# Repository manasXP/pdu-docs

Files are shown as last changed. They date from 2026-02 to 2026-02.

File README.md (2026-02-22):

# 30 kW Power Delivery Unit (PDU) — Design Documentation

Design documentation for a **30 kW DC fast-charging power module** intended for EV charging infrastructure. The module converts 3-phase AC to adjustable high-voltage DC, and 5 units stack via CAN bus to deliver 150 kW.

## Key Specifications

| Parameter | Value |
|---|---|
| Input | 3-phase 260–530 VAC, up to 60 A, PF ≥ 0.99 |
| Output | 150–1000 VDC, 0–100 A, 30 kW constant power |
| Efficiency | > 96% peak (SiC-based, targeting > 98%) |
| Topology | Vienna Rectifier PFC + 3-phase interleaved LLC DC-DC |
| Controller | STM32G474RE (170 MHz, HRTIM) |
| Stacking | 5 modules via CAN bus → 150 kW |
| Form factor | ~455 × 300 × 94 mm, fan-cooled, < 17 kg |
| Standards | IEC 61851-23, IEC 62368-1, UL 2202, CE, OCPP 1.6, ISO 15118 |

## Multi-Board Architecture

The PDU is split into 5 separate PCBs interconnected by power bus bars and signal harnesses:

| Board | Function | Layers | Size |
|---|---|---|---|
| **Power Entry** | AC input protection (NTC inrush, bypass relays), DC output contactor | 2 | 150 × 120 mm |
| **AC-DC** | Vienna Rectifier PFC — EMI filter, 3-phase rectification, DC bus caps | 6 | 250 × 180 mm |
| **DC-DC** | LLC Resonant converter — primary bridge, transformers, secondary rectifier | 6 | 250 × 180 mm |
| **Controller** | STM32G474RE, CAN bus, analog conditioning, OCPP/ISO 15118 | 4 | 120 × 100 mm |
| **Aux PSU** | Isolated supplies — gate drive (+18 V/−5 V), logic (3.3/5 V), fan (12 V) | 4 | 100 × 80 mm |

## Repository Structure

```
pdu-docs/
├── __init.md                          # Project definition and specifications
├── CLAUDE.md                          # Claude Code workspace guidance
│
├── docs/                              # Design documentation
│   ├── 01-Topology Selection.md       # Vienna PFC + 3-phase interleaved LLC
│   ├── 02-Magnetics Design.md        # LLC resonant tank, transformer, inductor
│   ├── 03-LLC Gain Curve Verification.md  # FHA + ngspice simulation
│   ├── 04-Thermal Budget.md          # Loss breakdown, junction temps, cooling
│   ├── 05-EMI Filter Design.md       # EN 55032 Class B, surge, inrush
│   ├── 06-Firmware Architecture.md   # STM32G474 HRTIM, ADC, control loops
│   ├── 06-Firmware-Design/           # Firmware implementation details (8 docs)
│   │   ├── __init.md                 # Index and reading order
│   │   ├── 01-Application State Machine.md
│   │   ├── 02-Power-On Sequence and Ramp Control.md
│   │   ├── 03-Fault State Machine and Recovery.md
│   │   ├── 04-LLC Burst Mode.md
│   │   ├── 05-CAN Master and Module Stacking.md
│   │   ├── 06-ADC Pipeline and DMA Configuration.md
│   │   └── 07-Neutral Point Balancing.md
│   ├── 07-BOM and Cost Analysis.md   # Per-module BOM, cost @ 100/500 qty
│   ├── 08-Power-On Sequence and Inrush Management.md
│   ├── 09-Protection and Safety.md   # OVP/OCP/OTP, insulation, hipot,compliance
│   ├── 10-Mechanical Integration.md  # Enclosure,heatsink,fans,bus bars,assembly
│   │
│   └── 07-PCB-Layout/                # Multi-board PCB layout documentation
│       ├── __init.md                  # 5-board overview and design targets
│       ├── 00-Board Partitioning.md   # Inter-board interfaces, connectors, grounding
│       ├── AC-DC/                     # Vienna PFC board (7 docs)
│       │   ├── __init.md
│       │   ├── 01-Stack-Up and Layer Assignment.md
│       │   ├── 02-Power Loop Analysis.md
│       │   ├── 03-Gate Driver Layout.md
│       │   ├── 04-Thermal Layout.md
│       │   ├── 05-EMI-Aware Layout.md
│       │   └── 06-Creepage and Clearance.md
│       ├── DC-DC/                     # LLC converter board (7 docs)
│       │   ├── __init.md
│       │   ├── 01-Stack-Up and Layer Assignment.md
│       │   ├── 02-Power Loop Analysis.md
│       │   ├── 03-Gate Driver Layout.md
│       │   ├── 04-Thermal Layout.md
│       │   ├── 05-EMI-Aware Layout.md
│       │   └── 06-Creepage and Clearance.md
│       ├── Controller/                # Digital control board (6 docs)
│       │   ├── __init.md
│       │   ├── 01-Stack-Up and Layer Assignment.md
│       │   ├── 02-Signal Integrity.md
│       │   ├── 03-Communication Interfaces.md
│       │   ├── 04-Power Distribution.md
│       │   └── 05-EMC and Grounding.md
│       ├── Aux-PSU/                   # Auxiliary power supply board (6 docs)
│       │   ├── __init.md
│       │   ├── 01-Stack-Up and Layer Assignment.md
│       │   ├── 02-Isolated Converter Layout.md
│       │   ├── 03-Thermal Layout.md
│       │   ├── 04-Output Filtering and Regulation.md
│       │   └── 05-Safety and Isolation.md
│       └── Power-Entry/               # Contactor and relay board (1 doc)
│           └── __init.md
│
│   └── 12-Project-Management/            # Consolidated project management
│       ├── __init.md                     # Epic overview, Gantt, milestones, gate reviews
│       ├── EP-01 Design Review and Procurement.md    (18 stories)
│       ├── EP-02 Rev A Prototype Build.md            (14 stories)
│       ├── EP-03 Firmware Bring-Up.md                (16 stories)
│       ├── EP-04 System Integration.md               (15 stories)
│       ├── EP-05 Rev B Prototype.md                  (12 stories)
│       ├── EP-06 Firmware Maturation.md              (14 stories)
│       ├── EP-07 Certification Prep.md               (13 stories)
│       ├── EP-08 Pre-Production Validation.md        (11 stories)
│       ├── EP-09 Production Release.md               (10 stories)
│       ├── Budget Estimate.md            # $390k–$615k detailed budget
│       ├── Risk Register.md              # 21 risks, 5×5 scoring matrix
│       └── Commissioning Procedure.md    # 7-stage field deployment
│
├── research/                          # Research notes and trade studies
│   ├── 3-Phase PFC Topology Selection.md
│   ├── DC-DC Topology Trade Study.md
│   ├── Commercial Reference Designs Survey.md
│   ├── EMC-EMI Limits and Filter Design.md
│   └── SiC Device Thermal Parameters.md
│
└── sim/                               # Simulation files
    ├── llc_fha_gain.py                # First Harmonic Approximation gain model
    ├── llc_ngspice_sweep.py           # ngspice parameter sweep automation
    ├── llc_halfbridge.cir             # SPICE netlist — LLC half-bridge
    ├── llc_sweep.cir                  # SPICE netlist — frequency sweep
    ├── llc_gain_curves.png            # FHA gain curves output
    ├── llc_spice_vs_fha.png           # SPICE vs FHA comparison
    └── llc_zvs_detail.png             # ZVS boundary detail plot
```

## Documentation Overview

### Design Documents (`docs/`)

| # | Document | Status |
|---|---|---|
| 01 | **Topology Selection** — Vienna PFC + 3-phase interleaved LLC | Approved |
| 02 | **Magnetics Design** — LLC resonant tank (Lr, Lm, Cr), transformer | Draft |
| 03 | **LLC Gain Curve Verification** — FHA model + ngspice validation | Draft |
| 04 | **Thermal Budget** — System losses, junction temperatures, cooling | Draft |
| 05 | **EMI Filter Design** — EN 55032 Class B, CM/DM filtering | Draft |
| 06 | **Firmware Architecture** — STM32G474RE HRTIM, control loops, CAN | Draft |
| 06 | **Firmware Design** — Implementation details: state machine, ramps, faults, burst mode, CAN master, ADC/DMA, NP balance (8 sub-documents) | Draft |
| 07 | **BOM and Cost Analysis** — Component selection, cost at volume | Draft |
| 07 | **PCB Layout** — Multi-board layout across 5 PCBs (29 sub-documents) | Draft |
| 08 | **Power-On Sequence** — Startup/shutdown, inrush, pre-charge | Draft |
| 09 | **Protection and Safety** — OVP/OCP/OTP, insulation, hipot, compliance | Draft |
| 10 | **Mechanical Integration** — Enclosure, heatsink, fans, bus bars | Draft |
| 12 | **Project Management** — 9 epics (123 stories), Gantt timeline, milestones, gate reviews, budget estimate, risk register, commissioning procedure (13 documents) | Draft |

### PCB Layout (`docs/07-PCB-Layout/`)

The PCB layout section contains **29 documents** organized by board:

- **Power Entry Board** (1 doc) — 2-layer, NTC inrush limiting, bypass relays, DC output contactor, AC/DC zone separation
- **AC-DC Board** (7 docs) — 6-layer, Vienna PFC power loops (≤10 nH), SiC gate drivers, 530 VAC creepage
- **DC-DC Board** (7 docs) — 6-layer, LLC primary loop (≤8 nH, critical margin), 4 kV primary-secondary isolation
- **Controller Board** (6 docs) — 4-layer digital, signal integrity, CAN/OCPP/ISO 15118 interfaces
- **Aux PSU Board** (6 docs) — 4-layer, flyback converter, reinforced isolation from 920 VDC bus

### Research Notes (`research/`)

Trade studies and component evaluations supporting the design decisions:
- PFC topology comparison (Vienna vs B6, Swiss, two-level VSI)
- DC-DC topology comparison (LLC vs DAB, PSFB, CLLC, SRC)
- Commercial reference design survey (Wolfspeed, ST, Infineon, onsemi, TI, ADI)
- EMC/EMI limits and filter design methodology
- SiC MOSFET thermal characterization and package comparison

### Simulations (`sim/`)

Python scripts and SPICE netlists for LLC resonant converter verification:
- First Harmonic Approximation (FHA) gain model
- ngspice transient simulation and frequency sweep
- Gain curve validation (FHA vs SPICE)
- ZVS boundary analysis

## Viewing These Documents

This repository is designed as an [Obsidian](https://obsidian.md/) vault. For the best experience:

1. Clone the repo
2. Open the folder as a vault in Obsidian
3. Navigate using `[[wiki links]]` — all internal links resolve within the vault

The documents are also readable as standard Markdown in any viewer (GitHub, VS Code, etc.), though `[[wiki links]]` will not be clickable outside Obsidian.

## Author

**Manas Pradhan**

## License

All rights reserved JouleWorX LLP 2025. This documentation is proprietary.

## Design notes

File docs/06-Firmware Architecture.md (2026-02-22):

---
tags: [PDU, firmware, STM32G474, HRTIM, Vienna-PFC, LLC, control]
created: 2026-02-22
---

# 06 – Firmware Architecture: STM32G474RE Control of Vienna PFC + 3-Phase Interleaved LLC

This document covers the complete firmware design for the 30 kW PDU using the STM32G474RE MCU to control a Vienna rectifier PFC front-end followed by a 3-phase interleaved LLC DC-DC stage.

---

## 1. STM32G474RE HRTIM Resource Map

### 1.1 HRTIM Architecture

The STM32G474RE includes **HRTIM v2**, running at 170 MHz system clock with an internal DLL at **5.44 GHz**, providing a minimum resolution of **184 ps**.

| Parameter | Value |
|---|---|
| System clock | 170 MHz |
| HRTIM DLL clock | 5.44 GHz |
| Minimum resolution | 184 ps |
| Timer units | 1 Master + 6 Slave (A, B, C, D, E, F) |
| Total PWM outputs | 12 (2 per slave timer: Tx1, Tx2) |
| Fault inputs | 5 (FLT1–FLT5) |
| ADC trigger events | 10 (ADC1TRGx, configurable per timer event) |

> [!note] Resolution calculation
> At 170 MHz PLL input, HRTIM DLL = 32 × 170 MHz = 5.44 GHz → period = 184 ps. Compare to a standard 16-bit timer at 170 MHz (5.88 ns resolution) — HRTIM is ~32× finer.

### 1.2 HRTIM Output Allocation

With 12 outputs (TA1/TA2 through TF1/TF2), the full 30 kW converter requires exactly **12 complementary outputs**: 6 for Vienna PFC + 6 for LLC.

#### Vienna PFC — 3 Switch Cells (Timers A, B, C)

The Vienna rectifier has 3 bidirectional switch cells, one per phase leg. Each cell requires one complementary PWM pair (top switch + bottom switch) with programmable dead-time.

| HRTIM Timer | Output Pair | Function | Switching Freq |
|---|---|---|---|
| Timer A | TA1 / TA2 | Phase A switch cell (S_A+, S_A−) | 48–65 kHz |
| Timer B | TB1 / TB2 | Phase B switch cell (S_B+, S_B−) | 48–65 kHz |
| Timer C | TC1 / TC2 | Phase C switch cell (S_C+, S_C−) | 48–65 kHz |

- Dead-time insertion: ~300 ns (SiC MOSFET, SCTWA90N65G2V-4 per [[01-Topology Selection]] §3.3)
- Phase interleaving: Timers A/B/C synchronized to Master, with compare registers in Master setting 120° offsets for PFC current ripple cancellation (effective ripple frequency 96–130 kHz)
- Duty cycle updated each PWM period by current-loop ISR

#### 3-Phase Interleaved LLC — 3 Half-Bridges (Timers D, E, F)

Each LLC phase is a half-bridge. Each half-bridge needs complementary drive with dead-time to ensure ZVS.

| HRTIM Timer | Output Pair | Function | Switching Freq |
|---|---|---|---|
| Timer D | TD1 / TD2 | LLC Phase 1 half-bridge (Q1_H, Q1_L) | 100–300 kHz |
| Timer E | TE1 / TE2 | LLC Phase 2 half-bridge (Q2_H, Q2_L) | 100–300 kHz |
| Timer F | TF1 / TF2 | LLC Phase 3 half-bridge (Q3_H, Q3_L) | 100–300 kHz |

- Dead-time: 80–150 ns (adjusted vs. operating frequency and ZVS condition)
- Variable frequency: period register (PERxR) updated each cycle via LLC voltage/current loop
- 120° phase interleaving maintained by master timer compare registers D/E/F (see Section 5.3)

> [!tip] Half-mode operation
> HRTIM "half mode" (HALF bit in TIMxCR = 1) automatically sets CMP1 = PER/2, guaranteeing 50% duty cycle at variable frequency — ideal for LLC half-bridges.

---

## 2. ADC Requirements

### 2.1 STM32G474RE ADC Instances

The G474RE has **5 × 12-bit ADC instances** (ADC1–ADC5), each capable of 4 Msps, with up to 42 total channels and 16-bit resolution via hardware oversampling. ADC1/ADC2 and ADC3/ADC4 are interleaved pairs sharing a common clock.

### 2.2 Signal List and ADC Allocation

#### Vienna PFC Signals

| Signal | Description | Sample Rate | ADC | Channel | Notes |
|---|---|---|---|---|---|
| I_A | Phase A input current | 48–65 kHz (every PWM period) | ADC1 | INJ group | Shunt or LEM HAL sensor |
| I_B | Phase B input current | 48–65 kHz | ADC2 | INJ group | Simultaneous with ADC1 |
| I_C | Phase C input current | 48–65 kHz | ADC3 | INJ group | Can derive from I_A + I_B |
| V_DC_bus | PFC output bus voltage | 48–65 kHz | ADC1 | INJ group | Resistor divider, ×½ |
| V_A | Grid phase A voltage | 48–65 kHz | ADC2 | INJ group | For PLL and feed-forward |
| V_B | Grid phase B voltage | 48–65 kHz | ADC3 | INJ group | |
| V_C | Grid phase C voltage | 48–65 kHz | ADC4 | INJ group | Derive Vγ or use all 3 |
| V_cap_top | Upper DC-link cap voltage | 1 kHz | ADC1 | REG group | Neutral point balance |
| V_cap_bot | Lower DC-link cap voltage | 1 kHz | ADC2 | REG group | Neutral point balance |

#### LLC DC-DC Signals

| Signal | Description | Sample Rate | ADC | Channel | Notes |
|---|---|---|---|---|---|
| V_out | Output DC voltage | 20 kHz | ADC4 | INJ group | Primary feedback for CV |
| I_out | Output DC current | 20 kHz | ADC5 | INJ group | Hall sensor, primary feedback for CC |
| I_LLC_ph1 | LLC phase 1 resonant current | 100 kHz | ADC1 | INJ group | Peak current / OCP sensing |
| I_LLC_ph2 | LLC phase 2 resonant current | 100 kHz | ADC2 | INJ group | |
| I_LLC_ph3 | LLC phase 3 resonant current | 100 kHz | ADC3 | INJ group | |

#### Temperature and Auxiliary Signals

| Signal | Description | Sample Rate | ADC | Notes |
|---|---|---|---|---|
| T_SiC_PFC | PFC SiC MOSFET heatsink NTC | 100 Hz | ADC4 | REG group, slow background scan |
| T_SiC_LLC | LLC SiC MOSFET heatsink NTC | 100 Hz | ADC5 | REG group |
| T_magnetics | Transformer / inductor NTC | 100 Hz | ADC4 | REG group |
| T_ambient | Inlet air temperature | 10 Hz | ADC5 | REG group |
| V_aux_12V | Auxiliary 12 V rail monitor | 100 Hz | ADC3 | REG group |

### 2.3 ADC Triggering and Synchronization

The G474 HRTIM generates 10 programmable ADC trigger events (ADC1TRG1–ADC1TRG5, ADC2TRG1–ADC2TRG5) that can be routed to any timer's reset, compare, or period event.

**PFC current sampling (center-of-PWM):**
- HRTIM Timer A, B, C each fire an ADC trigger at their CMP2 register, set to PER/2 (midpoint of on-time)
- This samples phase currents at the valley/midpoint where ripple is minimal (equivalent to average current sensing)
- `LL_ADC_INJ_SetTriggerSource(ADC1, LL_ADC_INJ_TRIG_EXT_HRTIM_TRG1)` → Timer A CMP2

**LLC output voltage/current sampling:**
- HRTIM Timer D fires ADC4/ADC5 injected trigger at its period event (resonant peak)
- Sampling at switching frequency (up to 300 kHz for LLC) requires ADC1–3 injected mode at 100 kHz minimum

**Slow background signals (temperatures, auxiliary rails):**
- ADC3/ADC4/ADC5 regular group in DMA scan mode, postscaler set to reduce effective rate to 100 Hz
- Triggered by HRTIM Master timer at rate-divided compare event

> [!warning] G474 ADC errata
> STM32G4 errata ES0430 notes issues when intermixing regular and injected channels with the same ADC instance and using DMA. Prefer dedicated ADC instances per group or use the oversampler on regular channels only.

---

## 3. STSW-30KWVRECT Reference Firmware Architecture

ST's **STSW-30KWVRECT** is the official reference firmware for the STDES-30KWVRECT 30 kW Vienna rectifier board using the STM32G474RE.

### 3.1 Software Layer Structure

```
Application Layer
├── State Machine (Init → Soft-Start → Run → Fault → Shutdown)
├── OCPP / Communication Interface (CAN to charger controller)
└── Supervisory (OTP, derating, fan speed, LED/status)

Control Layer (ISR-driven)
├── PFC Current Control ISR  [48–65 kHz, ~3 µs budget]
│   ├── ADC readback (phase currents, bus voltage, grid voltages)
│   ├── Clarke / Park transforms (abc → αβ → dq)
│   ├── SRF-PLL update (grid angle θ)
│   ├── d-axis and q-axis current PI controllers
│   ├── Inverse Park + SVM (Space Vector Modulation)
│   └── HRTIM duty-cycle update (TA1/TA2, TB1/TB2, TC1/TC2)
│
├── Bus Voltage Loop  [1 kHz, outer loop]
│   ├── V_DC filtered (2nd-order IIR)
│   ├── Voltage PI → I_d* reference
│   └── Anti-windup (back-calculation)
│
└── Neutral Point Balance  [1 kHz]
    └── V_cap differential PI → modulation index offset

Peripheral Drivers
├── HRTIM HAL/LL (6 timers, fault inputs)
├── ADC LL (5 instances, injected + regular)
├── CAN FD (FDCAN1 peripheral)
├── UART (debug, OCPP passthrough)
└── DMA (ADC, UART)
```

### 3.2 ISR Timing Budget

| ISR | Trigger | Period | Estimated execution |
|---|---|---|---|
| PFC_CurrentControl_ISR | HRTIM Master period event | 15–21 µs (48–65 kHz) | 2.5–3 µs |
| BusVoltage_ISR | TIM6 or HRTIM Master/64 | 1 ms | 0.5 µs |
| LLC_VoltageControl_ISR | HRTIM Timer D period event | Varies (2.5–10 µs) | 1 µs |
| CAN_Rx_ISR | FDCAN Rx FIFO | On demand | 0.3 µs |
| Fault_ISR | HRTIM FLT event | On demand | 0.1 µs (HW) |

At 170 MHz Cortex-M4, a 65 kHz ISR with 3 µs execution consumes **19.5%** of CPU — within budget for dual-loop control. The STM32G474's CORDIC and FMAC co-processors offload Park/Clarke transforms to reduce ISR execution time.

---

## 4. Vienna PFC Digital Control

### 4.1 dq-Frame Current Control

The Vienna rectifier is controlled in the synchronous (dq) reference frame, aligning the d-axis with the grid voltage vector so that:
- **I_d** controls active power (and DC bus voltage indirectly)
- **I_q** controls reactive power (set to 0 for unity PF)

**Control signal path:**

```
Grid voltages (V_abc) ──→ Clarke (αβ) ──→ Park (dq, using θ from PLL)
Phase currents (I_abc) ──→ Clarke ──→ Park → I_d_meas, I_q_meas

I_d* (from V_bus loop) ──→ [PI] ──→ V_d*
I_q* = 0              ──→ [PI] ──→ V_q*
                      + decoupling (ωL feedforward)

(V_d*, V_q*) ──→ Inverse Park ──→ (V_α*, V_β*) ──→ SVM ──→ HRTIM duty cycles
```

**Decoupling terms** (cross-coupling compensation):
```
V_d* = V_d_PI - ω·L·I_q + V_d_grid
V_q* = V_q_PI + ω·L·I_d + V_q_grid
```

**Typical PI gains (48–65 kHz sampling, L_boost ≈ 200 µH per phase, 700–920 V bus):**

| Loop | Bandwidth | K_p | K_i | Notes |
|---|---|---|---|---|
| d-axis current | 1–2 kHz | 0.8–1.5 Ω | 1,000–3,000 rad/s | Tuned for L/R time constant |
| q-axis current | 1–2 kHz | 0.8–1.5 Ω | 1,000–3,000 rad/s | Same structure as d-axis |
| DC bus voltage | 20–50 Hz | 0.01–0.05 | 5–20 rad/s | Outer loop, slow relative to current |

> [!note] Gain tuning method
> Use K_p = 2ζω_c·L and K_i = ω_c²·L/R, where ω_c = 2π × bandwidth. For L = 200 µH, R_winding = 20 mΩ, target bandwidth 1.5 kHz: K_p ≈ 0.94, K_i ≈ 1,776 rad/s.

### 4.2 Software PLL for Grid Synchronization

**Recommended PLL type: SRF-PLL (Synchronous Reference Frame PLL)**

The ST reference firmware (UM2975, STSW-VIENNARECT) uses an SRF-PLL. DSOGI-PLL is the preferred alternative for weak or distorted grids.

**SRF-PLL structure:**
```
V_abc ──→ Clarke (V_αβ) ──→ Park (V_dq using θ̂)
V_q ──→ PI (force V_q → 0) ──→ ω̂ ──→ integrator ──→ θ̂
```

| Parameter | Value | Notes |
|---|---|---|
| PLL type | SRF-PLL (DSOGI-PLL for distorted grid) | |
| Tracking range | 45–65 Hz | Per project spec |
| Bandwidth | 20–50 Hz (fast: up to 100 Hz) | Balance between noise rejection and tracking speed |
| Damping ζ | 0.707 (critically damped) | Standard choice |
| K_p (PLL PI) | 2ζω_n | ω_n = 2π × bandwidth |
| K_i (PLL PI) | ω_n² | |
| Sample rate | 48–65 kHz | Same as current-loop ISR |
| Frequency output | ω̂ → used for decoupling terms | |
| Angle output | θ̂ → used for Park transforms | |

**DSOGI-PLL** (recommended for noisy industrial grid or weak grid):
- Uses Second-Order Generalized Integrator (SOGI) as pre-filter to extract fundamental component
- Rejects harmonics before PLL, allows higher PLL bandwidth (500 rad/s vs. ~200 rad/s for SRF-PLL)
- Slightly higher computational cost; well within G474 budget

### 4.3 Bus Voltage Loop

| Parameter | Value |
|---|---|
| Target bus voltage | 700–920 VDC (active adjustment per output demand, see [[01-Topology Selection]] §4.4) |
| Control bandwidth | 20–50 Hz (1/10th of grid frequency) |
| Output | I_d* reference (active current demand) |
| Anti-windup | Back-calculation with tracking time constant T_t = √(T_i/T_p) |
| Voltage filter | 2nd-order Butterworth IIR, fc = 100 Hz (rejects 300 Hz ripple) |
| Soft-start | Ramp I_d* from 0 → rated over 200 ms (6 s total including LLC ramp) |
| Neutral-point balance | Separate P controller on (V_cap_top − V_cap_bot); adds offset to zero-sequence modulation |

---

## 5. LLC Frequency Control

### 5.1 Variable-Frequency Control via HRTIM Period Register

The LLC resonant converter is controlled by **PFM (Pulse Frequency Modulation)**. In HRTIM, switching frequency is set by writing the period register `PERxR` of each LLC timer (D, E, F).

**HRTIM period vs. frequency relationship:**
```
f_sw = f_HRTIM_DLL / PERxR
PERxR = f_HRTIM_DLL / f_sw
      = 5.44 × 10⁹ / f_sw

Example:
  f_sw = 200 kHz → PERxR = 27,200 ticks (5 ns resolution at this count)
  f_sw = 100 kHz → PERxR = 54,400 ticks
  f_sw = 300 kHz → PERxR = 18,133 ticks
```

**With HALF mode enabled** (HALF = 1 in TIMxCR):
- CMP1 auto-computed as PERxR/2 → 50% duty cycle guaranteed
- Dead-time registers (DTRx) set independently of duty cycle
- On each LLC control update: write new PERxR → HRTIM applies at next period boundary

**Period register update sequence** (to avoid glitches):
1. Preload enable: set PREEN bit (updates take effect at period boundary, not immediately)
2. Write new PERxR to shadow register
3. HRTIM automatically transfers shadow → active at next timer reset
4. If preload is disabled, write must be done after CMP event to avoid half-period glitch

### 5.2 CC/CV Outer Loop

The LLC operates in two modes:
- **CC mode** (constant current): I_out controlled by varying frequency
- **CV mode** (constant voltage): V_out controlled by varying frequency

**Control structure:**
```
CV mode:  V_out* ──→ [PI] ──→ Δf ──→ f_sw = f_nom + Δf ──→ PERxR update
CC mode:  I_out* ──→ [PI] ──→ Δf ──→ f_sw = f_nom + Δf ──→ PERxR update
Mode select: I_out > I_limit → switch to CC; V_out > V_limit → switch to CV
```

**Frequency-to-gain relationship:**
- Below resonance (f < f_r): gain increases as f decreases (ZCS risk)
- Above resonance (f > f_r): gain decreases as f increases (ZVS maintained)
- Operating range: f_r to 2×f_r (always above resonance in normal regulation)
- f_r ≈ 150.5 kHz = 1/(2π√(L_r·C_r)) — see [[02-Magnetics Design]] and [[03-LLC Gain Curve Verification]]

| Parameter | Value |
|---|---|
| Outer loop bandwidth | 500 Hz – 2 kHz (much slower than switching) |
| Frequency range | 100 kHz to 300 kHz (per [[01-Topology Selection]] §4.3) |
| K_p (voltage loop) | 0.001–0.01 (units: Hz/V) |
| K_i | 1–10 rad/s |
| Anti-windup | Clamp integrator when f_sw hits min/max limit |
| Sample rate for V_out / I_out | 20 kHz (LLC timer period event) |

### 5.3 Phase Interleaving at Variable Frequency

Maintaining 120° phase offset between the three LLC phases requires that the HRTIM master timer manages phase references, not just absolute timing.

**Implementation using HRTIM Master timer:**
```
Master timer: runs at same period as LLC slaves (PERxR_M = PERxR_D = PERxR_E = PERxR_F)

Master CMP1 ──→ resets Timer D (Phase 1, offset = 0°)
Master CMP2 ──→ resets Timer E (Phase 2, offset = PERxR/3)
Master CMP3 ──→ resets Timer F (Phase 3, offset = 2×PERxR/3)

On frequency update:
  new_PERxR = f_HRTIM_DLL / f_sw_new
  Master_CMP1 = 0
  Master_CMP2 = new_PERxR / 3
  Master_CMP3 = 2 × new_PERxR / 3
  Write all registers simultaneously using HRTIM burst mode or preload
```

> [!important] Simultaneous register update
> All period and compare registers must be updated atomically (in the same PWM cycle) to avoid transient phase imbalance during frequency steps. Enable preload on Master and all slave timers; write all values before the next Master period event triggers shadow transfer.

**TI C2000 application note SPRAD15** documents a similar approach for 3-phase interleaved LLC where CMPA/CMPB values for phase shift must be loaded simultaneously to prevent PWM ordering errors during frequency transitions.

### 5.4 Burst Mode for Light Load (< 3 kW, ~10%)

Below 10% load, variable frequency alone cannot maintain regulation efficiently (very high frequency → high switching losses, low gain). Burst mode is implemented:

**HRTIM Burst Mode Controller:**
- Hardware block within HRTIM that alternates between RUN and IDLE states
- In IDLE state: HRTIM outputs are forced to idle level (low for LLC switches)
- Burst period and duty cycle set by `HRTIM_BMPER` and `HRTIM_BMCMPR` registers
- Trigger: software sets burst mode active when LLC voltage PI output falls below threshold

**Burst mode activation threshold:**
```
Enter burst mode: f_sw demand > f_burst_threshold (e.g., 280 kHz)
Exit burst mode:  f_sw demand < f_run_threshold (e.g., 270 kHz) [hysteresis]
```

**During burst IDLE period:**
- LLC resonant tank rings down naturally (ZVS preserved for first post-burst cycle)
- Output capacitor supplies load
- ADC continues sampling; voltage loop integrator freezes (or decays slowly)

**Light-load efficiency improvement:**
- At 5% load, burst mode reduces switching events by 70–90%
- Core losses in LLC transformer proportional to switching frequency × duty of activity
- Burst frequency ~10–50 kHz; burst duty cycle adjusted by outer voltage loop

---

## 6. Inter-Module CAN Protocol for 5-Module Stacking

### 6.1 Physical Layer

| Parameter | Value |
|---|---|
| Interface | FDCAN1 (STM32G474 FDCAN peripheral) |
| Bit rate | 500 kbps nominal (data phase 2 Mbps for CAN FD) |
| Topology | Daisy-chain bus, 120 Ω termination at each end |
| Frame format | CAN 2.0B (29-bit extended ID) or CAN FD |
| Bus length | Up to 5 m within charger cabinet |

### 6.2 CAN Frame Structure

**Module address scheme:** Each module has a 4-bit node ID (0x0–0xF), configured via DIP switches or resistor-coded GPIO.

#### Status Frame (Module → Master, broadcast, 10 ms period)

| Bits | Field | Resolution | Range |
|---|---|---|---|
| 28:24 | Node ID [4:0] | — | 0–15 |
| 23:16 | Message type = 0x01 | — | Status |
| 15:4 | I_out measured [11:0] | 0.1 A/LSB | 0–100 A |
| 3:0 | Fault flags [3:0] | — | OVP, OCP, OTP, COM |
| +16 bits | V_out measured [15:0] | 0.1 V/LSB | 0–1000 V |
| +8 bits | Temperature [7:0] | 1°C/LSB | −40–215°C |
| +8 bits | Module state [7:0] | — | INIT/RUN/FAULT/IDLE |

#### Command Frame (Master → All modules, 10 ms period)

| Bits | Field | Resolution | Range |
|---|---|---|---|
| 28:24 | Destination (0x1F = broadcast) | — | |
| 23:16 | Message type = 0x02 | — | Command |
| 47:32 | V_ref [15:0] | 0.1 V/LSB | 150–1000 V |
| 63:48 | I_ref [15:0] | 0.1 A/LSB | 0–100 A |
| +8 bits | Enable flags | — | EN, CC_mode, CV_mode |

### 6.3 Current-Sharing Strategy

**Active current sharing with droop:**
```
I_ref_module_n = I_total_ref / N_active + K_droop × (I_avg − I_n_meas)

Where:
  N_active = number of enabled modules (1–5)
  K_droop  = droop gain (~0.05 A/A)
  I_avg    = mean of all modules' I_out (computed by master from status frames)
  I_n_meas = this module's measured output current
```

**Master module responsibilities:**
- Receives status frames from all slaves every 10 ms
- Computes I_avg and checks for imbalance (> 5% → log event)
- Broadcasts updated I_ref and V_ref every 10 ms
- Module selection: activates/deactivates modules based on total power demand
- Fault arbitration: if any module reports fault, master re-allocates current

**Slave module behavior on CAN timeout:**
- If no command frame received within 50 ms → reduce output to 50% rated
- If no command frame within 200 ms → shutdown (safety fail-safe)

---

## 7. Protection Implementation

### 7.1 Hardware Protection (< 1 µs response)

These protections use the STM32G474 analog comparators (COMP1–COMP7) routed directly to HRTIM fault inputs, bypassing firmware entirely.

| Protection | Mechanism | Threshold | Response | HRTIM Fault |
|---|---|---|---|---|
| OCP — PFC phase | COMP1/2/3 on shunt resistor | 1.3× rated (78 A peak) | < 200 ns | FLT1 → all PFC outputs → idle |
| OCP — LLC resonant | COMP4/5 on LLC current transformer | 2× rated peak | < 200 ns | FLT2 → LLC outputs → idle |
| OVP — DC bus | COMP6 on resistor divider | 966 V (920 V × 1.05) | < 1 µs | FLT3 → all outputs → idle |
| OVP — LLC output | COMP7 on output divider | 1050 V (Vout_max × 1.05) | < 1 µs | FLT4 → LLC outputs → idle |

**HRTIM fault response modes:**
- **CBC (Cycle-by-Cycle):** output forced idle for one period, auto-resets; used for soft current limiting
- **Latch:** output forced idle permanently until firmware clears; used for hard faults (OVP, destructive OCP)

### 7.2 Firmware Protection (1–10 ms response)

These protections are implemented in the control ISR or background task.

| Protection | Mechanism | Threshold | Response Time | Action |
|---|---|---|---|---|
| OTP — SiC junction | NTC ADC reading | > 100°C | 10 ms (background loop) | Derate output power, then shutdown at 115°C |
| OTP — magnetics | NTC ADC reading | > 120°C | 10 ms | Reduce switching frequency, then shutdown |
| OTP — ambient | NTC ADC reading | > 65°C | 100 ms | Enable fan boost, derate at 55°C |
| UVP — DC bus | Software threshold in voltage loop | < 600 V (min operating) | 1 ms (voltage ISR) | Disable LLC, hold PFC |
| Phase loss | SRF-PLL frequency deviation | ±5 Hz from nominal | 20 ms | Fault state |
| CAN timeout | Missing master frame counter | > 50 ms | — | Reduce to 50% rated |

### 7.3 Soft-Start and Inrush

- **Pre-charge relay**: closes via NTC thermistor circuit before main contactor to limit inrush to DC bus caps
- **Software soft-start**: ramp I_d* from 0 in PFC current loop over 200 ms; LLC V_ref ramp from V_initial to V_target over further 1–2 s
- **Total startup time**: ≤ 6 s (per project spec in [[__init]])

> [!info] For the complete power-on/off sequence including inrush calculations, NTC/relay/contactor specifications, timing diagrams, fault shutdown sequences, and cold-start analysis, see [[08-Power-On Sequence and Inrush Management]].

---

## 8. OCPP 1.6 and ISO 15118 Interface

### 8.1 Architecture Overview

The STM32G474RE power module does **not** run OCPP or ISO 15118 directly — these are handled by a higher-level **SECC (Supply Equipment Communication Controller)** or charger management module (typically an embedded Linux or RTOS-based board with Ethernet/Wi-Fi).

The power module interfaces to this controller via a simple **internal CAN or UART protocol**.

```
[EV Vehicle BMS] ←──── ISO 15118 (PLC on pilot line) ────→ [SECC / Charger Controller]
                                                                     │
                                                              OCPP 1.6 (Ethernet/4G)
                                                                     │
                                                           [Cloud / CSMS Backend]
                                                                     │
                                                      CAN bus or RS-485 (internal)
                                                                     │
                                                      ┌──────────────┴──────────────┐
                                                [PDU Module 1] ... [PDU Module 5]
                                                (STM32G474RE)      (STM32G474RE)
```

### 8.2 Internal CAN Messages from Charger Controller to PDU Modules

The charger controller translates ISO 15118/OCPP session parameters into simple setpoints sent to PDU modules:

| Message | Direction | Fields | Rate |
|---|---|---|---|
| Charger_Setpoint | Controller → PDU | V_target (V), I_target (A), mode (CC/CV/OFF), session_id | 100 ms |
| PDU_Status | PDU → Controller | V_out (V), I_out (A), P_out (W), T_max (°C), fault_code, state | 100 ms |
| PDU_Fault | PDU → Controller | fault_type, fault_severity (warn/shutdn), timestamp | On event |

### 8.3 OCPP 1.6 Relevant Actions (Charger Controller Level)

The power module firmware responds indirectly to these OCPP actions via the setpoint messages above:

| OCPP Action | Effect on PDU |
|---|---|
| `RemoteStartTransaction` | Controller sends Charger_Setpoint with I_target, V_target |
| `RemoteStopTransaction` | Controller sends I_target = 0, then OFF |
| `ChangeConfiguration` (max current) | Controller updates I_target in Charger_Setpoint |
| `MeterValues` | PDU_Status aggregated and uploaded as meter reading |
| `StatusNotification` | PDU fault_code mapped to OCPP status (Faulted, Available) |

### 8.4 ISO 15118 Interaction (Plug & Charge, V2G)

ISO 15118-2 (AC/DC charging) defines `CurrentDemand` and `PowerDelivery` messages. The SECC translates:

| ISO 15118 Parameter | Mapped to PDU |
|---|---|
| `EVTargetVoltage` | V_target in Charger_Setpoint |
| `EVTargetCurrent` | I_target in Charger_Setpoint |
| `EVMaximumVoltageLimit` | V_max clamp in PDU firmware |
| `EVMaximumCurrentLimit` | I_max clamp in PDU firmware |
| `ChargingComplete` | Controller sends OFF setpoint |

> [!note] OCPP 1.6 + ISO 15118 tunneling
> OCPP 1.6 does not natively carry ISO 15118 data. OCA's "Using ISO 15118 Plug & Charge with OCPP 1.6" spec defines a `DataTransfer` tunneling mechanism. For new designs, prefer OCPP 2.0.1 which has native ISO 15118 support.

---

## 9. Firmware Implementation Checklist

- [ ] HRTIM DLL calibration at startup (ST HAL: `HAL_HRTIM_DLLCalibrationStart`)
- [ ] ADC calibration (self-calibration on startup for all 5 instances)
- [ ] SRF-PLL pre-lock sequence on startup (ramp ω̂ from 0 to grid frequency before enabling current loop)
- [ ] LLC soft-start: begin at f_max (maximum attenuation) and ramp down toward f_r
- [ ] Preload enable on all LLC HRTIM timers before variable-frequency operation
- [ ] HRTIM fault inputs tested in hardware (inject fault signal via test point)
- [ ] CAN baud rate configuration (500 kbps) and node ID DIP switch read at init
- [ ] NTC thermistor lookup table (Steinhart-Hart coefficients for specific NTC part)
- [ ] State machine fault logging (fault code + timestamp to internal flash or EEPROM emulation)

---

## References

- [[01-Topology Selection]] — Vienna PFC + LLC topology rationale
- [[02-Magnetics Design]] — L_r, C_r, transformer design
- [[03-LLC Gain Curve Verification]] — Gain curve and ZVS boundary
- [[04-Thermal Budget]] — SiC junction temperatures and derating curves
- [[Commercial Reference Designs Survey]] — ST STDES-30KWVRECT, Wolfspeed CRD30DD12N-K

**Implementation detail sub-documents** (see [[06-Firmware-Design/__init|06-Firmware Design]]):
- [[06-Firmware-Design/01-Application State Machine|01-Application State Machine]] — 10-state FSM, transition table, pseudocode
- [[06-Firmware-Design/02-Power-On Sequence and Ramp Control|02-Power-On Sequence and Ramp Control]] — Init steps, PLL lock, PFC/LLC ramps
- [[06-Firmware-Design/03-Fault State Machine and Recovery|03-Fault State Machine and Recovery]] — Fault classification, derate curves, logging
- [[06-Firmware-Design/04-LLC Burst Mode|04-LLC Burst Mode]] — Light-load burst algorithm, HRTIM registers
- [[06-Firmware-Design/05-CAN Master and Module Stacking|05-CAN Master and Module Stacking]] — Master FSM, enable sequencing, failover
- [[06-Firmware-Design/06-ADC Pipeline and DMA Configuration|06-ADC Pipeline and DMA Configuration]] — DMA buffers, oversampling, filters
- [[06-Firmware-Design/07-Neutral Point Balancing|07-Neutral Point Balancing]] — P-controller, zero-sequence injection

**External references:**
- ST AN4539 Rev 5 — [HRTIM Cookbook](https://www.st.com/resource/en/application_note/an4539-hrtim-cookbook-stmicroelectronics.pdf)
- ST UM3011 — [STDES-30KWVRECT Getting Started](https://www.st.com/resource/en/user_manual/um3011-getting-started-with-the-stdes30kwvrect-30-kw-vienna-pfc-rectifier-reference-design-stmicroelectronics.pdf)
- ST STSW-30KWVRECT — [Firmware package](https://www.st.com/en/embedded-software/stsw-30kwvrect.html)
- Imperix — [SRF-PLL](https://imperix.com/doc/implementation/synchronous-reference-frame-pll) and [Vector current control](https://imperix.com/doc/implementation/vector-current-control)
- TI SPRAD15 — Three-Phase Interleaved LLC on C2000 Type-4 PWM
- Infineon EVAL-5K5W-3PH-LLC — [5.5 kW 3-Phase Interleaved LLC App Note](https://www.infineon.com/assets/row/public/documents/24/42/infineon-evaluation-board-eval-5k5w-3ph-llc-sic2-applicationnotes-en.pdf)
- ST STM32G4 HRTIM Training — [Product Training PDF](https://www.st.com/resource/en/product_training/STM32G4-WDG_TIMERS-High_Resolution_Timer_HRTIM.pdf)
- ST AN5346 — [STM32G4 ADC Use Tips](https://www.st.com/resource/en/application_note/an5346-stm32g4-adc-use-tips-and-recommendations-stmicroelectronics.pdf)
- OCA — [Using ISO 15118 Plug & Charge with OCPP 1.6](https://openchargealliance.org/wp-content/uploads/2023/11/ocpp_1_6_ISO_15118_v10.pdf)

---

## Revision History

| Rev | Date | Author | Changes |
|-----|---|---|---|
| 0.1 | 2026-02-22 | Manas Pradhan | Initial draft |

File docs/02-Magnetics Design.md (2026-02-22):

---
tags: [PDU, magnetics, LLC, transformer, resonant-tank, design]
created: 2026-02-21
status: draft
---

# Magnetics Design — 30 kW LLC DC-DC Stage

> [!summary] Key Results
> **Per phase (10 kW):** Lr = 43 µH, Cr = 26 nF, Lm = 258 µH (Ln = 6). Transformer: E65/32/27 core (3C97), Np = 21, Ns = 42, n = 2. Total magnetics loss ≈ 52 W/phase (99.5% magnetics efficiency).

## 1. Design Inputs

From [[01-Topology Selection]], §4:

| Parameter | Value |
|---|---|
| Topology | 3-phase interleaved LLC half-bridge |
| Power per phase | 10 kW |
| DC bus input (Vbus) | 650–920 VDC (actively adjusted by PFC) |
| Output voltage (Vo) | 200–1000 VDC |
| Constant-power range | 300–1000 VDC at 30 kW total |
| Resonant frequency (fr) | 150 kHz |
| Switching frequency range | 100–300 kHz |
| Target efficiency | >98% (DC-DC stage) |

**Half-bridge drive:** The primary sees Vbus/2 square wave. At Vbus = 800 V, the fundamental amplitude of the half-bridge square wave is:

$$V_{in,1} = \frac{2}{\pi} \cdot \frac{V_{bus}}{2} = \frac{2 \times 800}{\pi \times 2} = 255 \text{ V (rms: 180 V)}$$

## 2. Turns Ratio Selection

### 2.1 Methodology

The transformer turns ratio n = Ns/Np sets the relationship between input and output voltage at unity gain (M = 1). For an LLC half-bridge at resonance:

$$V_o = n \cdot \frac{V_{bus}}{2}$$

Rearranging: n = 2·Vo / Vbus.

### 2.2 Gain Requirements

The LLC voltage gain M is defined as:

$$M = \frac{V_o}{n \cdot V_{bus}/2}$$

With active bus voltage adjustment (650–920 V), we can set Vbus to minimize the gain excursion. The gain at each operating point for a given n:

| Vo (V) | Vbus (V) | n = 1.5 | n = 2.0 | n = 2.5 |
|---|---|---|---|---|
| 200 | 650 | 0.41 | 0.62 | 0.77 |
| 300 | 650 | 0.62 | 0.92 | 1.15 |
| 600 | 750 | 1.07 | 1.60 | 2.00 |
| 800 | 800 | 1.33 | 2.00 | 2.50 |
| 1000 | 920 | 1.45 | 2.17 | 2.72 |

> [!warning] These gains are absolute Vo/(n·Vbus/2). For LLC, M is referenced to the transformer primary. The LLC gain M = Vo / (n · Vbus/2) must stay within achievable range (typically 0.5–1.3 for practical Q values).

Let me recalculate properly. For LLC half-bridge, the output voltage is:

$$V_o = M \cdot n \cdot \frac{V_{bus}}{2}$$

So the required gain is:

$$M = \frac{V_o}{n \cdot V_{bus}/2}$$

### 2.3 Gain Table with n = 2

| Operating Point | Vo (V) | Po/phase (W) | Io/phase (A) | Vbus (V) | n·Vbus/2 | M required |
|---|---|---|---|---|---|---|
| Min voltage | 200 | 6,667 | 33.3 | 650 | 650 | 0.31 |
| Low voltage | 300 | 10,000 | 33.3 | 700 | 700 | 0.43 |
| Mid-low | 400 | 10,000 | 25.0 | 700 | 700 | 0.57 |
| **Design center** | **600** | **10,000** | **16.7** | **750** | **750** | **0.80** |
| High voltage | 800 | 10,000 | 12.5 | 800 | 800 | 1.00 |
| Max voltage | 1000 | 10,000 | 10.0 | 920 | 920 | 1.09 |

> [!note] With n = 2
> - At 800 V output / 800 V bus → M = 1.00 (exact resonance, peak efficiency)
> - At 1000 V output / 920 V bus → M = 1.09 (slightly below resonance, ZVS maintained — see [[03-LLC Gain Curve Verification]])
> - At 300 V output / 700 V bus → M = 0.43 (well above resonance, power is derated)
> - Maximum gain M_max = 1.09 is comfortably achievable with LLC while maintaining ZVS

**Decision: n = 2 (Ns:Np = 2:1).** This places the unity-gain point at the sweet spot of 800 V output (most common CCS charging voltage for modern EVs at 80–90% SoC) and keeps the maximum gain requirement modest at 1.09.

## 3. Resonant Tank Design (Lr, Lm, Cr)

### 3.1 First Harmonic Approximation (FHA) Model

The LLC resonant converter is analyzed using FHA, where the square-wave input and rectified output are replaced by their fundamental sinusoidal components.

**Equivalent AC load resistance:**

$$R_{ac} = \frac{8 n^2}{\pi^2} \cdot \frac{V_o^2}{P_o}$$

At the design center (Vo = 600 V, Po = 10 kW):

$$R_{ac} = \frac{8 \times 4}{\pi^2} \cdot \frac{600^2}{10000} = \frac{32}{9.87} \times 36 = 3.24 \times 36 = 116.7 \text{ Ω}$$

### 3.2 Quality Factor and Characteristic Impedance

The quality factor Q and inductance ratio Ln are the two key design parameters:

$$Q = \frac{\sqrt{L_r / C_r}}{R_{ac}} = \frac{Z_0}{R_{ac}}$$

$$L_n = \frac{L_m}{L_r}$$

**Design guidelines:**
- **Q:** Lower Q → wider gain bandwidth, less sensitivity to load. Target Q = 0.3–0.5 at design center.
- **Ln:** Lower Ln → higher gain range but more magnetizing current (higher conduction loss). Ln = 5–7 is typical for wide-output applications.

**Selected: Q = 0.35, Ln = 6** at the design center (Vo = 600 V, Po = 10 kW).

### 3.3 Resonant Component Calculation

**Characteristic impedance:**

$$Z_0 = Q \times R_{ac} = 0.35 \times 116.7 = 40.8 \text{ Ω}$$

**Resonant frequency:**

$$\omega_r = 2\pi f_r = 2\pi \times 150000 = 942{,}478 \text{ rad/s}$$

**Resonant inductance Lr:**

$$L_r = \frac{Z_0}{\omega_r} = \frac{40.8}{942478} = 43.3 \text{ µH} \approx 43 \text{ µH}$$

**Resonant capacitance Cr:**

$$C_r = \frac{1}{\omega_r \cdot Z_0} = \frac{1}{942478 \times 40.8} = 26.0 \text{ nF} \approx 26 \text{ nF}$$

**Magnetizing inductance Lm:**

$$L_m = L_n \times L_r = 6 \times 43 = 258 \text{ µH}$$

### 3.4 Verification — Resonant Frequency

$$f_r = \frac{1}{2\pi\sqrt{L_r C_r}} = \frac{1}{2\pi\sqrt{43 \times 10^{-6} \times 26 \times 10^{-9}}} = \frac{1}{2\pi \times 33.43 \times 10^{-6}} \times 10^{-1}$$

$$= \frac{1}{2\pi \times 3.343 \times 10^{-7}} \times 10^{1} = \frac{1}{2.101 \times 10^{-6}} \times 10^{1}$$

Let's compute directly:

$$L_r \cdot C_r = 43 \times 10^{-6} \times 26 \times 10^{-9} = 1.118 \times 10^{-12}$$

$$\sqrt{L_r C_r} = 1.057 \times 10^{-6} \text{ s}$$

$$f_r = \frac{1}{2\pi \times 1.057 \times 10^{-6}} = \frac{1}{6.641 \times 10^{-6}} = 150.6 \text{ kHz}  ✓$$

### 3.5 LLC Gain Equation

The LLC voltage gain as a function of normalized frequency fn = fs/fr:

$$M(f_n, Q, L_n) = \frac{f_n^2 \cdot (L_n - 1)}{\sqrt{\left(f_n^2 \cdot L_n - 1\right)^2 + f_n^2 \cdot (f_n^2 - 1)^2 \cdot L_n^2 \cdot Q^2}}$$

> [!note] Second resonant frequency
> The LLC has a second resonance at:
> $$f_{r2} = \frac{f_r}{\sqrt{1 + 1/L_n}} = \frac{150}{\sqrt{1.167}} = 138.9 \text{ kHz}$$
> Below fr2, the converter loses ZVS capability. The switching frequency must stay above fr2 under all conditions.

### 3.6 Gain and Q Verification Across Operating Range

| Vo (V) | Po (W) | Io (A) | Vbus (V) | M req'd | Rac (Ω) | Q at Rac | fn (calc) | fs (kHz) |
|---|---|---|---|---|---|---|---|---|
| 200 | 6,667 | 33.3 | 650 | 0.31 | 19.4 | 2.10 | >2.0 | >300 |
| 300 | 10,000 | 33.3 | 700 | 0.43 | 29.2 | 1.40 | ~1.8 | ~270 |
| 400 | 10,000 | 25.0 | 700 | 0.57 | 51.9 | 0.79 | ~1.5 | ~225 |
| **600** | **10,000** | **16.7** | **750** | **0.80** | **116.7** | **0.35** | **~1.15** | **~173** |
| 800 | 10,000 | 12.5 | 800 | 1.00 | 207.4 | 0.20 | 1.00 | 150 |
| 1000 | 10,000 | 10.0 | 920 | 1.09 | 324.1 | 0.13 | ~0.96 | ~143 |

> [!tip] Key observations
> - At 800 V: M = 1.0, fs = fr = 150 kHz — perfect resonance, peak efficiency
> - At 1000 V: M = 1.09, fs ≈ 143 kHz (below fr but above fr2 = 139 kHz) — ZVS maintained with ~3% margin. Confirmed by [[03-LLC Gain Curve Verification]].
> - At 300 V: fs = ~270 kHz, well within 300 kHz limit. Efficiency drops but power is derated.
> - At 200 V: fs approaching 300 kHz limit. This is the extreme derated case (only 6.7 kW). Acceptable.

## 4. Transformer Design

### 4.1 Core Selection

**Requirements per phase:**
- Power: 10 kW
- Frequency: 100–300 kHz (design center 150 kHz)
- Primary voltage: 375–460 Vpk (half-bridge at 750–920 V bus)
- Turns ratio: n = 2 (Ns:Np = 2:1)

**Core: E65/32/27 (3C97 ferrite)**

| Parameter | Value |
|---|---|
| Core type | E65/32/27 |
| Material | 3C97 (Ferroxcube) or N97 (TDK) |
| Effective area (Ae) | 535 mm² |
| Effective volume (Ve) | 79,400 mm³ |
| Effective length (le) | 148 mm |
| Window area (Aw) | ~530 mm² |
| Saturation (Bsat at 100°C) | ~350 mT |
| Core loss density (150 kHz, 60 mT) | ~80 kW/m³ |

> [!note] Why E65/32/27
> This is the workhorse core for 5–15 kW LLC converters in the 100–200 kHz range. The large window area accommodates the interleaved litz-wire windings. 3C97 material is optimized for 100–300 kHz with low core loss and stable permeability.

### 4.2 Flux Density Calculation

For an LLC half-bridge, the peak flux in the core is set by the magnetizing current (Lm and Vbus):

$$B_{peak} = \frac{V_{bus}}{2 \cdot 4 \cdot N_p \cdot A_e \cdot f_s}$$

At the design center (Vbus = 750 V, fs = 150 kHz):

$$B_{peak} = \frac{750}{2 \times 4 \times N_p \times 535 \times 10^{-6} \times 150000} = \frac{750}{642 \times N_p \times 10^{-3}}$$

$$= \frac{750}{0.642 \times N_p}$$

For Bpeak = 60 mT:

$$N_p = \frac{750}{0.642 \times 0.060} = \frac{750}{0.0385} = 19.5 \rightarrow N_p = 20$$

Checking at worst case (Vbus = 920 V, fs = 143 kHz — minimum frequency at 1000 V output with Vbus_max = 920 V):

$$B_{peak} = \frac{920}{2 \times 4 \times 20 \times 535 \times 10^{-6} \times 143000} = \frac{920}{0.612} = 75 \text{ mT}$$

This is still well below saturation but leaves less margin. Increase to **Np = 21** for safety:

$$B_{peak} = \frac{920}{2 \times 4 \times 21 \times 535 \times 10^{-6} \times 143000} = \frac{920}{0.643} = 71.5 \text{ mT}$$

**Selected: Np = 21, Ns = 42** (n = 2 maintained). Bpeak = 57–72 mT across the operating range. Well below 350 mT saturation — margin of ~5:1.

### 4.3 Winding Design

**Primary winding:**
- Turns: Np = 21
- RMS current: Ipri,rms ≈ Ipri,load + Imag

At design center (600 V, 10 kW):

$$I_{pri,load,rms} = \frac{\pi}{2\sqrt{2}} \cdot \frac{n \cdot I_o}{1} = \frac{\pi}{2\sqrt{2}} \times \frac{2 \times 16.7}{1} = 1.11 \times 33.3 = 37.0 \text{ A (peak of fundamental)}$$

$$I_{pri,load,rms} = \frac{37.0}{\sqrt{2}} = 26.2 \text{ A rms}$$

Magnetizing current (peak):

$$I_{mag,pk} = \frac{V_{bus}}{2 \cdot 4 \cdot L_m \cdot f_s} = \frac{750}{2 \times 4 \times 258 \times 10^{-6} \times 150000} = \frac{750}{309.6} = 2.42 \text{ A}$$

$$I_{mag,rms} = \frac{2.42}{\sqrt{3}} = 1.40 \text{ A}$$

Total primary RMS current (worst case at 300 V, 10 kW):

$$I_{pri,rms} \approx 28 \text{ A (at design center), up to ~37 A at 300 V output)}$$

- Wire: **Litz wire, 44 AWG × 800 strands** (equivalent cross-section ≈ 2.0 mm², current density ≈ 14 A/mm² at 28 A)
- 2 layers of ~10.5 turns each

**Secondary winding:**
- Turns: Ns = 42
- RMS current at design center: Isec,rms = Ipri,rms / n = 28 / 2 = 14 A (reflected; actual secondary current peaks at low Vo)
- At 300 V, 33.3 A output: Isec,rms ≈ 26 A
- Wire: **Litz wire, 44 AWG × 400 strands** (equivalent cross-section ≈ 1.0 mm²)
- 4 layers of ~10.5 turns each

### 4.4 Winding Interleaving

To minimize proximity-effect losses and reduce leakage inductance, use a **P-S-P-S sandwich** structure:

```
         ┌─────────────────────┐
         │   Core (top half)   │
         ├─────────────────────┤
Bobbin → │  P1 (10-11 turns)   │  ← Primary layer 1
         │  S1 (21 turns)      │  ← Secondary layer 1+2
         │  P2 (10-11 turns)   │  ← Primary layer 2
         │  S2 (21 turns)      │  ← Secondary layer 3+4
         ├─────────────────────┤
         │   Core (bottom)     │
         └─────────────────────┘
```

Benefits:
- Reduces MMF peaks to half compared to non-interleaved winding
- Controls leakage inductance (useful for integrating Lr)
- Reduces AC winding resistance by ~4× vs. non-interleaved

### 4.5 Leakage Inductance — Integrated Lr

The resonant inductance Lr = 43 µH can potentially be integrated as the transformer's leakage inductance. For a P-S-P-S structure:

$$L_{leak} \approx \frac{\mu_0 \cdot N_p^2 \cdot l_w}{3 \cdot p^2 \cdot h_w} \cdot \left( m \cdot d_c + (m-1) \cdot d_{ins} \right)$$

Where p = number of interleaving sections, m = number of winding layers per section, and d_ins = insulation thickness.

**Practical estimate:** For an E65 core with P-S-P-S sandwich and standard interlayer insulation (~0.5 mm), the leakage inductance is typically 5–15 µH. This is well below the required 43 µH.

> [!warning] Discrete Lr likely required
> The integrated leakage inductance (~10 µH) covers only ~25% of the required 43 µH. A discrete resonant inductor is needed for the remaining ~33 µH, or the insulation spacing can be increased to boost leakage — but this sacrifices coupling and increases winding losses.
>
> **Recommendation:** Use a **combination approach** — design the transformer for ~10 µH leakage, and add a discrete inductor of ~33 µH in series.

### 4.6 Core Loss Estimate

Using the improved generalized Steinmetz equation (iGSE) for non-sinusoidal waveforms. For LLC near resonance, the magnetizing current is approximately triangular, so the effective Bac ≈ Bpeak.

At design center (Bpeak = 57 mT, fs = 150 kHz, 3C97 material):

Steinmetz parameters for 3C97 at 100°C: k = 3.2, α = 1.46, β = 2.75 (approximate):

$$P_{core} = k \cdot f^{\alpha} \cdot B^{\beta} \cdot V_e$$

$$P_{core} = 3.2 \times (150)^{1.46} \times (57)^{2.75} \times 79.4 \times 10^{-6}$$

Using the manufacturer's loss curve directly: at 150 kHz, 60 mT, 3C97 gives approximately **80 kW/m³**.

$$P_{core} = 80 \times 10^3 \times 79.4 \times 10^{-6} = 6.4 \text{ W}$$

At the worst case (72 mT, 143 kHz — 1000 V output at Vbus = 920 V):

$$P_{core} \approx 140 \text{ kW/m}^3 \times 79.4 \times 10^{-6} = 11.1 \text{ W}$$

**Transformer core loss: 6–11 W** depending on operating point.

### 4.7 Copper Loss Estimate

**DC resistance (primary):**

Litz wire 44 AWG × 800 strands, mean turn length (MTL) for E65 ≈ 130 mm:

$$R_{DC,pri} = \frac{\rho \cdot l}{A} = \frac{1.72 \times 10^{-8} \times 21 \times 0.130}{2.0 \times 10^{-6}} = 24 \text{ mΩ}$$

With AC resistance factor Fac ≈ 1.5 for well-interleaved litz at 150 kHz:

$$R_{AC,pri} = F_{ac} \times R_{DC,pri} = 1.5 \times 24 = 36 \text{ mΩ}$$

$$P_{Cu,pri} = I_{rms}^2 \times R_{AC} = 28^2 \times 0.036 = 28.2 \text{ W}$$

**DC resistance (secondary):**

Litz wire 44 AWG × 400 strands, MTL ≈ 140 mm, Ns = 42:

$$R_{DC,sec} = \frac{1.72 \times 10^{-8} \times 42 \times 0.140}{1.0 \times 10^{-6}} = 101 \text{ mΩ}$$

$$R_{AC,sec} = 1.5 \times 101 = 152 \text{ mΩ}$$

At worst case (300 V, 33.3 A, Isec ≈ 26 Arms reflected to secondary):

$$P_{Cu,sec} = 14^2 \times 0.152 = 29.8 \text{ W (at design center)}$$

> [!note] Copper loss is load-dependent and peaks at low output voltage / high current operating points. At the 800 V design point, primary current drops to ~20 A and copper losses fall significantly.

**Total transformer copper loss: 30–58 W** (design center to worst case).

### 4.8 Transformer Thermal Estimate

Total transformer loss at design center: Pcore + Pcu ≈ 6 + 58 = 64 W (worst case at 300 V/33.3 A).

Typical thermal resistance for E65 core with forced-air cooling (2–3 m/s airflow): Rth ≈ 5–8 °C/W for the core, ~3 °C/W overall with good airflow design.

At 64 W total loss: ΔT ≈ 64 × 3 = 192°C — **too high for natural/low airflow**.

> [!warning] Thermal management is critical
> At worst-case loading, the transformer dissipates ~64 W. This requires:
> - Dedicated forced-air cooling duct (>3 m/s airflow over the core)
> - OR increase wire gauge (reduce current density to <10 A/mm²)
> - OR use a larger core (E71 or dual E65 cores)
>
> At the typical 800 V operating point, losses drop to ~25 W, which is manageable.
> Since most real-world charging occurs at 400–800 V, the average thermal load is much lower than worst case.

**Design action:** Size the cooling system for 50 W/phase transformer dissipation (90th percentile operating point). The 64 W worst case at 300 V is a transient condition (low SoC charging, EV battery heats up and moves past this quickly).

## 5. Resonant Inductor (Lr)

### 5.1 Integrated vs. Discrete

As discussed in §4.5, the transformer leakage provides only ~10 µH of the required 43 µH. A discrete inductor is needed for the remaining ~33 µH.

**Strategy: 10 µH integrated (transformer leakage) + 33 µH discrete.**

### 5.2 Discrete Inductor Design

| Parameter | Value |
|---|---|
| Inductance | 33 µH |
| RMS current | 28 A (design center), 37 A (worst case) |
| Peak current | ~52 A |
| Frequency | 100–300 kHz |
| Core | RM14 / PQ40/40 in 3C97 ferrite |
| Gap | Air gap to set inductance and prevent saturation |

**Core selection: PQ40/40 (3C97)**

| Parameter | Value |
|---|---|
| Ae | 201 mm² |
| Ve | 37,600 mm³ |
| le | 187 mm |
| Aw | ~220 mm² |

**Air gap calculation:**

$$l_g = \frac{\mu_0 \cdot N^2 \cdot A_e}{L} - \frac{l_e}{\mu_r}$$

For N = 15 turns, L = 33 µH:

$$l_g = \frac{4\pi \times 10^{-7} \times 225 \times 201 \times 10^{-6}}{33 \times 10^{-6}} - \frac{0.187}{2500}$$

$$l_g = \frac{56.8 \times 10^{-9}}{33 \times 10^{-6}} - 7.5 \times 10^{-5} = 1.72 \times 10^{-3} - 0.075 \times 10^{-3} = 1.65 \text{ mm}$$

**Gap: ~1.6 mm total (0.8 mm per leg for center-gap design).**

**Peak flux check:**

$$B_{peak} = \frac{L \cdot I_{peak}}{N \cdot A_e} = \frac{33 \times 10^{-6} \times 52}{15 \times 201 \times 10^{-6}} = \frac{1716 \times 10^{-6}}{3015 \times 10^{-6}} = 569 \text{ mT}$$

This exceeds saturation. Need more turns or larger core. Increase to **N = 24 turns**:

$$B_{peak} = \frac{33 \times 10^{-6} \times 52}{24 \times 201 \times 10^{-6}} = \frac{1.716 \times 10^{-3}}{4.824 \times 10^{-3}} = 356 \text{ mT}$$

Still close to saturation for ferrite. Use **PQ50/50** or add distributed gap. Alternatively, use a **powder core (Kool Mµ or XFlux from Magnetics Inc.)** which handles DC bias much better:

> [!tip] Powder core alternative
> A **Kool Mµ 77439 toroid** (µ = 60, OD = 39 mm, Ae = 107 mm²) with 33 turns provides:
> - L = 33 µH at zero bias
> - Soft saturation characteristic — inductance rolls off gracefully at high current
> - No discrete air gap needed (distributed gap)
> - Better EMI (no fringing flux)
> - Core loss is higher than ferrite but acceptable for a small inductor
>
> **Recommendation: Kool Mµ toroid for the discrete Lr portion.**

### 5.3 Inductor Loss Estimate

For a Kool Mµ toroid at 150 kHz, the AC flux swing is small (most of the flux is DC bias from the magnetizing current component). Estimated:

- Core loss: ~3 W
- Copper loss (24 turns, litz wire): ~5 W

**Total discrete Lr loss: ~8 W**

## 6. Resonant Capacitor (Cr)

### 6.1 Requirements

| Parameter | Value |
|---|---|
| Capacitance | 26 nF |
| RMS current | 28 A (design center), 37 A (worst case) |
| Voltage rating | ≥1200 V (capacitor sees Vbus/2 + resonant voltage; worst case ~460 V + resonant swing at Vbus = 920 V) |
| ESR | <50 mΩ target for low loss |
| Type | C0G/NP0 MLCC or polypropylene film |

### 6.2 Component Selection

**Option A: C0G/NP0 MLCC (preferred)**

High-voltage C0G capacitors (e.g., TDK C series, CGA series):
- TDK CGA9N4C0G2J103J230KA: 10 nF, 630 V, 2220 size, C0G
- 3 in series = 3.33 nF at 1890 V rating
- 8 parallel strings of 3-in-series = 26.7 nF at 1890 V

Total: **24 capacitors** (8P × 3S configuration).

RMS current per capacitor: 28 / 8 = 3.5 A — check ripple current rating. C0G MLCCs typically handle 2–5 Arms in 2220 size, so this is at the limit.

> [!note] C0G MLCCs
> - Zero voltage coefficient (no capacitance loss under DC bias unlike X7R)
> - Very low ESR (~5 mΩ per cap, total string ESR ~19 mΩ)
> - Temperature stable (-55 to +125°C)
> - Compact footprint on PCB

**Option B: Polypropylene film capacitor**

- EPCOS/TDK B32652 series: 22 nF or 33 nF, 1250 V, polypropylene film
- Single component solution (e.g., 22 nF + 4.7 nF in parallel ≈ 26.7 nF)
- Higher ripple current capability (~5–10 Arms)
- Larger physical size (~30 × 20 × 15 mm each)

**Decision: C0G MLCC array (Option A)** for compactness and low ESR. Polypropylene film as backup if thermal or ripple current issues arise during prototyping.

### 6.3 Capacitor Loss

$$P_{Cr} = I_{rms}^2 \times ESR = 28^2 \times 0.019 = 14.9 \text{ W}$$

> [!warning] 15 W in the capacitor array is significant. Review:
> - Actual ESR may be lower (C0G MLCCs at 150 kHz can be <3 mΩ per cap, giving total <6 mΩ and ~4.7 W)
> - If ESR loss is too high, add more parallel strings or switch to film capacitors
>
> **Revised estimate with measured ESR (~6 mΩ total): Pcr ≈ 4.7 W**

## 7. Loss Budget Summary (Per Phase, 10 kW)

| Component | Loss (W) | Notes |
|---|---|---|
| **Transformer core** | 6–11 | 3C97, E65/32/27, 57–72 mT |
| **Transformer copper** | 30–58 | Litz wire, interleaved P-S-P-S |
| **Discrete inductor (Lr)** | 8 | Kool Mµ toroid, 33 µH |
| **Resonant capacitor (Cr)** | 5 | C0G MLCC array, ~6 mΩ ESR |
| **Total magnetics** | **49–81** | Range: 800 V nom to 300 V worst case |

At the 800 V design point (M = 1.0, peak efficiency):
- Transformer core: 6 W
- Transformer copper: ~18 W (reduced current at 12.5 A output)
- Inductor: 5 W
- Capacitor: 3 W
- **Total: ~32 W → 99.7% magnetics efficiency**

At the 600 V design center (typical charging):
- **Total: ~52 W → 99.5% magnetics efficiency**

At the 300 V worst case (derated to 10 kW):
- **Total: ~81 W → 99.2% magnetics efficiency**

### 7.1 Budget Check Against System Target

The DC-DC stage target is >98% efficiency. The magnetics loss is only part of the total:

| Loss Component (per phase) | Estimated (W) | % of 10 kW |
|---|---|---|
| Magnetics (this document) | 52 | 0.52% |
| Primary MOSFETs (conduction + switching) | ~40 | 0.40% |
| Secondary diodes (conduction) | ~60 | 0.60% |
| Gate drive + control | ~5 | 0.05% |
| PCB traces + connectors | ~10 | 0.10% |
| **Total DC-DC loss** | **~167** | **1.67%** |
| **DC-DC efficiency** | | **~98.3%** |

> [!tip] The magnetics loss budget of ~52 W (0.52% of 10 kW) leaves sufficient margin for the semiconductor and parasitic losses to stay within the 98% DC-DC efficiency target.

## 8. Bill of Materials — Magnetics (Per Phase)

| Component | Part / Specification | Qty | Notes |
|---|---|-----|---|
| Transformer core | E65/32/27, 3C97 (Ferroxcube) | 1 set | Core pair |
| Transformer bobbin | B65/32 (Ferroxcube) | 1 | With pin header |
| Primary winding | Litz 44 AWG × 800 strands, 21 turns | — | 2 layers, interleaved |
| Secondary winding | Litz 44 AWG × 400 strands, 42 turns | — | 4 layers, interleaved |
| Interlayer insulation | Kapton tape, 0.05 mm × 3 layers | — | 5 kV isolation class |
| Discrete resonant inductor | Kool Mµ 77439 toroid + 24T litz wire | 1 | 33 µH, Magnetics Inc. |
| Resonant capacitor | TDK CGA9N4C0G2J103J, 10 nF, 630 V, 2220 | 24 | 8P × 3S = 26.7 nF |

**× 3 phases for the complete 30 kW module.**

## 9. Design Risks and Open Items

| Risk / Item | Status | Mitigation |
|---|---|---|
| Lr at 1000 V — fs drops near fr2 (139 kHz) | **Resolved** | Vbus_max raised to 920 V → M = 1.09, fs ≈ 143 kHz, ZVS maintained (see [[03-LLC Gain Curve Verification]]) |
| Transformer thermal at 300 V / 33 A | Open | Size cooling for 50 W/phase; verify with CFD |
| Cr ripple current in MLCC | Open | Measure ESR at 150 kHz on prototype; switch to film if needed |
| Integrated vs. discrete Lr trade-off | Decided | Hybrid: 10 µH integrated + 33 µH discrete |
| Litz wire sourcing (44 AWG × 800) | Open | Confirm availability; 46 AWG × 1200 is an alternative |
| Core thermal interface to heatsink | Open | Thermal pad between core and chassis; include in thermal design |

## 10. Next Steps

- [x] SPICE simulation of LLC resonant tank — verify gain curve and ZVS boundary → [[03-LLC Gain Curve Verification]]
- [ ] Thermal simulation — transformer and inductor in forced-air duct (CFD pending, see [[04-Thermal Budget]] §10)
- [ ] Prototype winding — build one transformer, measure leakage inductance
- [ ] Cr ESR measurement at 150 kHz

## 11. References

- [[01-Topology Selection]] — Architecture and LLC specifications
- Ferroxcube E65/32/27 datasheet — core dimensions and material properties
- Magnetics Inc. Kool Mµ powder core catalog — toroid selection guide
- TDK CGA MLCC catalog — high-voltage C0G capacitors
- R. Erickson & D. Maksimović, *Fundamentals of Power Electronics*, 3rd ed. — LLC analysis methodology
- B. Lu, W. Liu, et al., "Optimal Design Methodology for LLC Resonant Converter," IEEE APEC 2006
- Ferroxcube Application Note — "Design of Planar Power Transformers"

---

## Revision History

| Rev | Date | Author | Changes |
|-----|---|---|---|
| 0.1 | 2026-02-22 | Manas Pradhan | Initial draft |

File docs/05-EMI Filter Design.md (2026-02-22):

---
tags: [PDU, EMI, EMC, filter, Vienna, conducted-emissions, EN-55032]
created: 2026-02-22
status: draft
---

# EMI Filter Design — 30 kW PDU Input Stage

> [!summary] Key Results
> Two-stage LC filter: CM choke 1 (3.3 mH nanocrystalline) + CM choke 2 (1.0 mH MnZn ferrite) + DM capacitors (2.2 µF X2 per phase) + Y-caps (22 nF Y2 per line). Total filter attenuation >55 dB at 150 kHz. Estimated filter volume ~0.8 L, mass ~2.5 kg. Meets EN 55032 Class B with ≥6 dB design margin.

## 1. EMC Requirements

### 1.1 Applicable Standards

| Standard | Scope | Applies to |
|---|---|---|
| **EN 55032 (CISPR 32) Class B** | Conducted emissions, 150 kHz – 30 MHz | Primary EMC target for CE marking |
| **EN 61000-3-12** | Harmonic currents (16–75 A/phase) | Input current distortion |
| **EN 61000-4-2/3/4/5/6/8/11** | Immunity (ESD, surge, EFT, RF, dips) | Via IEC 61851-21-2 for EVSE |
| IEC 61851-21-2 | EMC for EV charging equipment | Master standard referencing EN 61000 series |

### 1.2 EN 55032 Class B Conducted Emission Limits

| Frequency Range | Quasi-Peak Limit (dBµV) | Average Limit (dBµV) |
|---|---|---|
| 150 kHz – 500 kHz | 66 → 56 (log-linear) | 56 → 46 (log-linear) |
| 500 kHz – 5 MHz | 56 | 46 |
| 5 MHz – 30 MHz | 60 | 50 |

> [!note] The 150–500 kHz range is the most critical band for this design. The Vienna rectifier's first in-band switching harmonics (3rd–4th of fsw) land squarely here, where the limit slopes from 66 dBµV down to 56 dBµV.

### 1.3 EN 61000-3-12 Harmonic Current Limits

For 3-phase balanced equipment at Rsce = 33 (typical public grid):

| Harmonic | Limit (% of Iref) | Absolute at 43 A ref (A) |
|---|---|---|
| 5th | 10.7% | 4.6 |
| 7th | 7.2% | 3.1 |
| 11th | 3.1% | 1.3 |
| 13th | 2.0% | 0.9 |
| THC | 13% | 5.6 |

The Vienna PFC with dq-frame current control achieves THDi < 3% at full load (per [[01-Topology Selection]] §7). Harmonic compliance is met by the active PFC — no passive harmonic filter needed.

### 1.4 Immunity Test Levels (IEC 61851-21-2)

| Test | Standard | Level | Specification |
|---|---|---|---|
| ESD | EN 61000-4-2 | 3 | ±6 kV contact, ±8 kV air |
| Radiated RF | EN 61000-4-3 | 3 | 10 V/m, 80 MHz – 1 GHz |
| EFT/Burst | EN 61000-4-4 | 3 / 2 | 2 kV (power) / 1 kV (signal) |
| Surge | EN 61000-4-5 | 3 | 2 kV L-E, 1 kV L-L |
| Conducted RF | EN 61000-4-6 | 3 | 10 Vrms, 150 kHz – 80 MHz |
| Voltage dips | EN 61000-4-11 | Per table | 0%, 40%, 70% dip; 250-cycle interruption |

The input EMI filter also provides surge attenuation. A dedicated metal-oxide varistor (MOV) stage handles the 2 kV surge per EN 61000-4-5.

## 2. Noise Source Analysis

### 2.1 Vienna Rectifier Switching Noise

From [[01-Topology Selection]] §3.3:
- Switching frequency: 48–65 kHz per switch cell
- 3-level topology → effective ripple frequency 96–130 kHz
- SiC MOSFETs (SCTWA90N65G2V-4): dV/dt ≈ 20–35 kV/µs

**Differential-mode (DM) noise spectrum:**

The Vienna rectifier produces a 3-level PWM voltage at each phase. The first switching harmonics:

| Harmonic | At fsw = 48 kHz (kHz) | At fsw = 65 kHz (kHz) | In EN 55032 band? |
|---|---|---|---|
| 1st | 48 | 65 | No |
| 2nd | 96 | 130 | No |
| **3rd** | **144** | **195** | Marginal / **Yes** |
| **4th** | **192** | **260** | **Yes** |
| 5th | 240 | 325 | Yes |

The 3-level switching reduces DM noise compared to 2-level by ~6 dB (halved voltage step). Unfiltered DM noise at the first in-band harmonic (~150–200 kHz) is estimated at **100–110 dBµV**.

Required DM attenuation at 150 kHz:

$$A_{DM,req} = 110 - 66 + 6 = 50 \text{ dB (with 6 dB margin)}$$

### 2.2 Common-Mode (CM) Noise Sources

| CM Parasitic | Typical Value | Impact |
|---|---|---|
| SiC MOSFET drain-to-heatsink (Cdh) | 50–100 pF per device | Dominant below 5 MHz |
| LLC transformer interwinding (Cw) | 10–50 pF (litz wire) | Significant 1–10 MHz |
| Heatsink-to-PE chassis (Chp) | 10–100 pF | Path to LISN measurement |
| Gate driver isolation (Cio) | 2–5 pF (STGAP2SiC) | Negligible |

At dV/dt = 35 kV/µs and Cdh = 100 pF per device (6 PFC MOSFETs):

$$I_{CM,peak} = C_{total} \times \frac{dV}{dt} = 600 \times 10^{-12} \times 35 \times 10^{9} = 21 \text{ A peak (impulse)}$$

This CM current impulse is very short-lived but produces broadband noise extending to 30+ MHz. Estimated unfiltered CM noise: **90–100 dBµV** in the 150 kHz – 5 MHz range.

Required CM attenuation at 150 kHz:

$$A_{CM,req} = 100 - 66 + 6 = 40 \text{ dB (with 6 dB margin)}$$

### 2.3 LLC Stage Noise

The LLC DC-DC stage operates at 100–300 kHz with ZVS, which significantly reduces high-frequency emissions. However:
- Transformer CM currents (interwinding capacitance) couple to the output
- Output rectifier diode ringing creates broadband noise at the DC output
- These are attenuated by the DC bus capacitor bank between PFC and LLC stages

The **input** EMI filter addresses AC-side conducted emissions. LLC noise reaches the AC input through the DC bus → PFC → input path, attenuated by at least 40 dB by the PFC control loop and bus capacitors.

## 3. Filter Topology

### 3.1 Two-Stage CM/DM Filter

```
AC Input    ┌────────┐    ┌──────┐    ┌────────┐    ┌──────┐    To PFC
  L1 ───────┤        ├────┤ Cx1  ├────┤        ├────┤ Cx2  ├──── L1'
  L2 ───────┤ CM     ├────┤ (DM) ├────┤ CM     ├────┤ (DM) ├──── L2'
  L3 ───────┤ Choke 1├────┤      ├────┤ Choke 2├────┤      ├──── L3'
  PE ───┬───┤        ├──┬─┤      ├──┬─┤        ├──┬─┤      ├──── PE
        │   └────────┘  │ └──────┘  │ └────────┘  │ └──────┘
        │               │           │              │
       MOV             Cy1         Cy2            Cy3
       (surge)       (Y-caps)    (Y-caps)       (Y-caps)
```

**Stage 1 (grid-facing):** Large CM choke (Lcm1) + X-capacitors (Cx1) + Y-capacitors (Cy1)
- Primary attenuation at 150–500 kHz
- Handles bulk energy of conducted noise
- Nanocrystalline core for high impedance at low frequency

**Stage 2 (PFC-facing):** Smaller CM choke (Lcm2) + X-capacitors (Cx2) + Y-capacitors (Cy2/Cy3)
- High-frequency attenuation (1–30 MHz)
- MnZn ferrite core for stable impedance at high frequency
- Cleans up residual noise and CM ringing

### 3.2 DM Filtering

The DM filter relies on:
1. **Leakage inductance of CM chokes** — typically 0.5–2% of Lcm → provides ~15–50 µH of DM inductance per stage
2. **X-capacitors** between phases
3. **PFC boost inductors** (external to the EMI filter) provide additional DM attenuation — typically 100–300 µH per phase, giving >40 dB DM rejection at 150 kHz

> [!tip] The Vienna PFC boost inductors are part of the DM filter
> Each boost inductor (~150 µH per phase) combined with the DC bus capacitors forms a low-pass filter with a corner frequency well below 150 kHz. This provides ≥40 dB of DM attenuation at the first in-band harmonic — so the dedicated DM filter only needs to contribute an additional ~10–15 dB.

## 4. Component Selection

### 4.1 CM Choke 1 — Nanocrystalline (Grid-Side)

| Parameter | Value |
|---|---|
| Inductance (CM) | 3.3 mH |
| Core material | Nanocrystalline (VITROPERM 500F, Vacuumschmelze) |
| Core size | W914 toroid (OD ≈ 80 mm) or equivalent |
| Winding | 3-phase, 15–20 turns per winding |
| Rated current | 60 A |
| Leakage inductance (DM) | ~30–50 µH (1–1.5% of Lcm) |
| Impedance at 150 kHz | >2 kΩ |
| Impedance at 1 MHz | >5 kΩ |
| Saturation current | >80 A (peak, including inrush) |
| Temperature rating | 130°C |

> [!note] Why nanocrystalline
> Nanocrystalline cores (µr ~ 30,000–80,000) provide 3–5× higher CM inductance per unit volume compared to MnZn ferrite. They maintain high impedance from 10 kHz to 1 MHz — ideal for the first-stage CM choke where the 150–500 kHz band needs maximum attenuation. The Vacuumschmelze VITROPERM W914 or Magnetec M-403 are common choices for 30 kW PFC filters.

**Candidate parts:**
- Vacuumschmelze T60006-L2080-W914 (VITROPERM 500F, 80 mm OD)
- Magnetec M-403-A (nanocrystalline, 3-phase, 60 A rated)
- Schaffner RD3132-80 (complete 3-phase CM choke module)

### 4.2 CM Choke 2 — MnZn Ferrite (PFC-Side)

| Parameter | Value |
|---|---|
| Inductance (CM) | 1.0 mH |
| Core material | MnZn ferrite (TDK PC95 or Ferroxcube 3E6) |
| Core size | 2× stacked R42 toroids (OD ≈ 42 mm) |
| Winding | 3-phase, 8–10 turns per winding |
| Rated current | 60 A |
| Leakage inductance (DM) | ~10–20 µH |
| Impedance at 1 MHz | >3 kΩ |
| Impedance at 10 MHz | >1 kΩ |

MnZn ferrite excels at high frequency (1–30 MHz) where nanocrystalline cores lose effectiveness due to winding capacitance.

### 4.3 X-Capacitors (DM)

| Parameter | Stage 1 (Cx1) | Stage 2 (Cx2) |
|---|---|---|
| Capacitance | 2.2 µF per phase pair | 1.0 µF per phase pair |
| Voltage | 310 VAC (X2 rated) | 310 VAC (X2 rated) |
| Quantity | 3 (L1-L2, L2-L3, L3-L1) | 3 |
| Type | Metallized polypropylene film | Metallized polypropylene film |
| Self-discharge | <1 s to 34 V (per EN 60384-14) | <1 s |

**Candidate:** EPCOS/TDK B32924 series (2.2 µF, 310 VAC, X2, 27.5 mm pitch).

Total X-capacitance per phase pair: 3.2 µF. This provides DM filtering corner frequency with the CM choke leakage:

$$f_{DM} = \frac{1}{2\pi\sqrt{L_{leak} \times C_x}} = \frac{1}{2\pi\sqrt{40 \times 10^{-6} \times 3.2 \times 10^{-6}}} = 14 \text{ kHz}$$

At 150 kHz (10× the corner), DM attenuation is ~40 dB per stage.

### 4.4 Y-Capacitors (CM)

| Parameter | Value |
|---|---|
| Capacitance | 22 nF per line (L-to-PE) |
| Voltage | 250 VAC (Y2 rated) |
| Quantity | 6 total (2 per line, distributed at Cy1 and Cy2 positions) |
| Type | Ceramic disc, Y2 safety rated |
| Leakage current | <3.5 mA total (per IEC 61140, <10 mA for fixed equipment) |

**Leakage current check:**

$$I_{leak} = 2\pi f \times C_{total} \times V_{line} = 2\pi \times 50 \times (6 \times 22 \times 10^{-9}) \times 400 = 16.6 \text{ mA}$$

> [!warning] Leakage current exceeds 10 mA limit
> At 6 × 22 nF = 132 nF total Y-capacitance and 400 VAC line voltage, the 50 Hz leakage is ~17 mA. This exceeds the IEC 61140 / EN 55032 protective-earth current limit of 10 mA for Class I equipment.
>
> **Mitigation options:**
> - Reduce to 10 nF per line → 6 × 10 nF = 60 nF → I_leak = 7.5 mA ✓
> - Or use a split Y-cap arrangement (Y-caps to DC bus midpoint instead of PE) which does not contribute to PE leakage
>
> **Decision: 10 nF Y2 per line, 6 total** → 7.5 mA leakage, meets <10 mA limit.

### 4.5 Surge Protection (MOV)

| Parameter | Value |
|---|---|
| Type | Metal-oxide varistor (MOV) |
| Placement | Input side (before CM choke 1) |
| Configuration | 3 × L-PE + 3 × L-L (delta + star) |
| L-PE varistor | 680 VAC (e.g., EPCOS B72220S0681K101) |
| L-L varistor | 680 VAC |
| Surge rating | 2 kV / 1.2/50 µs (per EN 61000-4-5 Level 3) |
| Clamping voltage | <1.8 kV at 500 A |

## 5. Filter Attenuation Verification

### 5.1 CM Attenuation

Each CM stage provides attenuation based on the LC resonance:

**Stage 1:** Lcm1 = 3.3 mH, Cy1 = 30 nF (3 × 10 nF)

$$f_{CM1} = \frac{1}{2\pi\sqrt{3.3 \times 10^{-3} \times 30 \times 10^{-9}}} = 16 \text{ kHz}$$

At 150 kHz (~10× corner): attenuation = -40 dB (2nd order LC).

**Stage 2:** Lcm2 = 1.0 mH, Cy2 = 30 nF

$$f_{CM2} = \frac{1}{2\pi\sqrt{1.0 \times 10^{-3} \times 30 \times 10^{-9}}} = 29 \text{ kHz}$$

At 150 kHz (~5× corner): attenuation = -28 dB.

**Total CM attenuation at 150 kHz: ~68 dB** (both stages cascaded, with ~10 dB deduction for non-ideal coupling → **~58 dB effective**).

Required: 40 dB. **Margin: ~18 dB. ✓**

### 5.2 DM Attenuation

**EMI filter DM path:** Lleakage (40 µH per stage) + X-caps (3.2 µF per stage) + PFC boost inductor (~150 µH).

DM attenuation from EMI filter alone at 150 kHz:

Stage 1: -40 dB (fcorner = 14 kHz, ×10)
Stage 2: -34 dB (fcorner = 20 kHz, ×7.5)

Subtotal from EMI filter: -74 dB (theoretical), derate to **~55 dB effective** for parasitic coupling.

PFC boost inductor adds another **~20 dB** at 150 kHz.

**Total DM attenuation at 150 kHz: ~75 dB effective.**

Required: 50 dB. **Margin: ~25 dB. ✓**

### 5.3 Attenuation Summary

| Frequency | CM Noise (dBµV) | CM Atten. (dB) | CM at LISN | DM Noise (dBµV) | DM Atten. (dB) | DM at LISN | Limit QP (dBµV) | Margin (dB) |
|---|---|---|---|---|---|---|---|---|
| 150 kHz | 100 | 58 | 42 | 110 | 75 | 35 | 66 | >24 |
| 500 kHz | 85 | 72 | 13 | 90 | 90 | 0 | 56 | >43 |
| 1 MHz | 80 | 80 | 0 | 75 | 95 | 0 | 56 | >56 |
| 5 MHz | 70 | 60 | 10 | 55 | 95 | 0 | 56 | >46 |
| 10 MHz | 60 | 45 | 15 | 40 | 95 | 0 | 60 | >45 |

> [!success] All operating points meet EN 55032 Class B with ≥6 dB margin. The 150 kHz point is the tightest, with ~24 dB margin. This provides a comfortable buffer for PCB layout parasitics, component tolerances, and production spread.

## 6. Physical Implementation

### 6.1 Filter Layout

```
AC input     [MOV]  [CM1]   [Cx1]  [Cy1]  [CM2]   [Cx2]  [Cy2]   To PFC
connector    stage   3.3mH   2.2µF  10nF   1.0mH   1.0µF  10nF    stage
   ↓          ↓       ↓       ↓      ↓       ↓       ↓      ↓
 ┌──┐      ┌──┐   ┌──────┐ ┌──┐  ┌──┐   ┌──────┐ ┌──┐  ┌──┐
 │  │      │  │   │      │ │  │  │  │   │      │ │  │  │  │
 └──┘      └──┘   └──────┘ └──┘  └──┘   └──────┘ └──┘  └──┘
  30mm      25mm    80mm     30mm  15mm    45mm     25mm  15mm
                     ↑                      ↑
              Nanocrystalline         MnZn ferrite
               toroid core           stacked toroids
```

### 6.2 Volume and Weight Estimate

| Component | Volume (cm³) | Weight (g) | Qty |
|---|---|---|-----|
| CM choke 1 (3.3 mH nanocrystalline) | 250 | 800 | 1 |
| CM choke 2 (1.0 mH MnZn) | 80 | 250 | 1 |
| X-capacitors (all) | 120 | 200 | 6 |
| Y-capacitors (all) | 15 | 30 | 6 |
| MOV array | 40 | 100 | 6 |
| PCB + mounting | 100 | 200 | 1 |
| Wiring / bus bars | 50 | 150 | — |
| **Total EMI filter** | **~655** | **~1730** | |

**Volume: ~0.66 L** (~5% of 12.8 L enclosure volume)
**Weight: ~1.7 kg** (~10% of 17 kg target)

> [!tip] The 3-level Vienna topology pays off here — a 2-level PFC would require ~40% larger DM filter components, adding ~0.3 L and ~0.7 kg.

### 6.3 Thermal Considerations

From [[04-Thermal Budget]]:
- EMI filter estimated loss: 15 W (CM choke core loss + capacitor ESR)
- Filter is located near the AC input, upstream of the PFC heatsink
- Receives fresh ambient air from fans → component temperatures stay below 80°C
- Nanocrystalline cores are rated to 130°C — ample margin

## 7. Inrush Current Limiting

The EMI filter X-capacitors (total ~9.6 µF across 3 phase pairs) and DC bus capacitors create a large inrush current at power-on.

### 7.1 Pre-Charge Circuit

| Parameter | Value |
|---|---|
| Method | NTC + bypass relay |
| NTC resistance (cold) | 10 Ω per phase |
| NTC steady-state resistance | <0.1 Ω (self-heated) |
| Bypass relay | 60 A rated, engages after soft-start complete |
| Soft-start time | ~3 s (NTC phase) + ~3 s (PFC ramp) = ≤6 s total |

Alternative: active pre-charge using the PFC MOSFETs in linear mode during startup. This eliminates the NTC but requires firmware support — available in the STSW-30KWVRECT reference firmware.

> [!info] For detailed inrush current calculations, NTC sizing, bypass relay selection, output contactor specification, and complete startup/shutdown timing, see [[08-Power-On Sequence and Inrush Management]].

## 8. Design for Immunity

### 8.1 Surge (EN 61000-4-5)

- 2 kV L-E, 1 kV L-L handled by the MOV array (§4.5)
- CM choke 1 provides additional surge impedance
- DC bus capacitors absorb residual energy

### 8.2 EFT/Burst (EN 61000-4-4)

- 2 kV on power lines
- The CM chokes and X-capacitors attenuate EFT pulses (5 ns rise, 50 ns duration)
- Y-capacitors divert CM EFT energy to PE

### 8.3 Conducted RF Immunity (EN 61000-4-6)

- 10 Vrms, 150 kHz – 80 MHz
- The two-stage EMI filter provides >40 dB rejection across this band
- Additional decoupling at the MCU and CAN interface

### 8.4 ESD (EN 61000-4-2)

- Not an EMI filter issue — handled by enclosure design (metal chassis, grounded connectors)
- TVS diodes on signal interfaces (CAN, UART)

## 9. Bill of Materials — EMI Filter

| Component | Part / Specification | Qty | Notes |
|---|---|-----|---|
| CM Choke 1 | VITROPERM W914, 3.3 mH, 60 A, 3-phase | 1 | Nanocrystalline toroid |
| CM Choke 2 | MnZn ferrite R42 stacked, 1.0 mH, 60 A | 1 | TDK PC95 or 3E6 |
| X-capacitor (Cx1) | 2.2 µF, 310 VAC, X2 (EPCOS B32924) | 3 | L-L, delta config |
| X-capacitor (Cx2) | 1.0 µF, 310 VAC, X2 | 3 | L-L, delta config |
| Y-capacitor (Cy) | 10 nF, 250 VAC, Y2 ceramic disc | 6 | L-PE, distributed |
| MOV (L-PE) | 680 VAC, 20 kA surge (EPCOS B72220S0681K101) | 3 | Star to PE |
| MOV (L-L) | 680 VAC, 20 kA surge | 3 | Delta between phases |
| NTC thermistor | 10 Ω cold, 60 A bypass relay | 3 | Inrush limiting |
| Bypass relay | 60 A, 600 VAC, normally open | 1 | Engages after soft-start |
| Discharge resistors | 1 MΩ across each X-cap | 6 | IEC 60384-14 compliance |

## 10. Design Risks and Open Items

| Risk / Item | Severity | Status | Mitigation |
|---|---|---|---|
| CM choke saturation during surge | Medium | Open | Verify surge current vs. nanocrystalline core saturation; add gap if needed |
| Y-cap leakage current margin (7.5 mA vs. 10 mA limit) | Low | Acceptable | 25% margin; use split-Y to midpoint if needed |
| PCB layout coupling between filter stages | Medium | Open | Maintain ≥20 mm separation between stage 1 and stage 2; shield partition |
| CM choke resonance with Y-caps | Low | Open | Verify no resonance peak in 150 kHz – 30 MHz band; add damping resistor if needed |
| NTC cold start at −30°C ambient | Low | Open | NTC resistance higher when cold — verify inrush stays within breaker trip curve |
| Filter insertion loss vs. frequency — prototype measurement | Medium | Planned | Measure with network analyzer before compliance testing |

## 11. Next Steps

- [ ] Procure CM choke samples (nanocrystalline + MnZn) and measure impedance vs. frequency
- [ ] Network analyzer measurement of filter insertion loss (CM and DM)
- [ ] Pre-compliance conducted emissions scan on prototype
- [ ] Verify surge withstand with MOV array (EN 61000-4-5 Level 3)
- [ ] EFT and conducted RF immunity testing per IEC 61851-21-2
- [ ] Finalize NTC + relay sizing for −30°C cold start

## 12. References

- [[01-Topology Selection]] — Vienna PFC switching frequency, semiconductor BOM
- [[04-Thermal Budget]] — EMI filter loss allocation (15 W)
- [[EMC-EMI Limits and Filter Design]] — Detailed limits tables and design references
- EN 55032:2015+A11:2020 — Conducted emission limits for multimedia equipment
- IEC 61851-21-2 — EMC requirements for EV charging equipment
- EN 61000-3-12 — Harmonic current limits for >16 A equipment
- Vacuumschmelze VITROPERM 500F — Nanocrystalline core datasheet and selection guide
- EPCOS/TDK B32924 — X2 capacitor datasheet
- Microchip MSCSICPFC/REF5 — 30 kW SiC Vienna PFC reference design (EMI filter section)
- Wolfspeed PRD-08907 — Mitigating EMI with SiC in grid-connected converters

---

## Revision History

| Rev | Date | Author | Changes |
|-----|---|---|---|
| 0.1 | 2026-02-22 | Manas Pradhan | Initial draft |

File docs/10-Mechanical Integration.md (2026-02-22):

---
tags: [PDU, mechanical, enclosure, thermal, heatsink]
created: 2026-02-22
status: draft
aliases: [Mechanical Integration, Enclosure Design]
---

# 10 — Mechanical Integration

## 1. Overview

This document defines the mechanical integration of the 30 kW PDU module, covering how four PCBs, the shared heatsink assembly, fan system, bus bars, signal harnesses, and external connectors are packaged into a single hot-swappable enclosure.

### 1.1 Scope

The mechanical design addresses:

- **Enclosure** — sheet metal housing with EMC shielding, rack-mount interface, and serviceability features
- **Heatsink** — forced-air cooled extrusion shared between the AC-DC and DC-DC power boards
- **Fan system** — axial fans with PWM speed control and dust filtration
- **Bus bars** — laminated DC bus interconnect and high-current output bars
- **Board mounting** — standoffs, heatsink attachment, vibration resistance
- **Connectors** — all external and internal electrical interfaces
- **Airflow path** — front-to-rear forced convection through heatsink fins

### 1.2 Form Factor

| Parameter | Value |
|---|---|
| Dimensions (W × D × H) | 455 × 300 × 94 mm |
| Rack format | 3U × half-rack width (or 2U full-width variant) |
| Weight target | < 17 kg |
| Module stacking | 5 modules per 150 kW rack via CAN bus |
| Insertion method | Slide-rail hot-swap, blind-mate DC output |

### 1.3 Design Philosophy

1. **Serviceability** — each board is independently replaceable without removing the heatsink or other boards. Signal harnesses use latching connectors for tool-free disconnect.
2. **Thermal performance** — direct MOSFET-to-heatsink mounting with low-resistance TIM; heatsink sized for full 30 kW at 45°C ambient without derating.
3. **EMC shielding** — continuous conductive contact at all panel joints; filtered cable entries; internal partitioning between power and control sections.
4. **Manufacturability** — sheet metal enclosure uses standard bend radii and hardware; heatsink is a single extrusion cut to length.

---

## 2. Enclosure Design

### 2.1 Material and Finish

| Property | Specification |
|---|---|
| Material | Aluminum 6061-T6, 1.2 mm walls / 1.6 mm baseplate |
| Surface treatment | Chromate conversion coating (MIL-DTL-5541, Type I, Class 3) |
| Exterior finish | Powder coat, RAL 7016 (anthracite grey), 60–80 µm |
| EMC conductivity | Chromate under powder coat on mating surfaces; bare aluminum or conductive gasket at panel joints |

> [!tip] Why 6061-T6?
> Provides good strength-to-weight ratio (yield 276 MPa), machinability, and corrosion resistance. 1.2 mm sheet keeps weight under budget while providing adequate stiffness for rack-mount loads.

### 2.2 IP Rating

- **IP20 (baseline):** Top and bottom panels include ventilation slots for direct airflow. Suitable for indoor cabinet installations where the outer enclosure provides weather protection.
- **IP54 (option):** All ventilation sealed; cooling via air-to-air heat exchanger or sealed recirculating loop. Adds ~2 kg and ~15% thermal derating.

### 2.3 Panel Layout

**Front panel (455 × 94 mm):**
- AC input connector (3-phase + N + PE), left side
- CAN bus port (DB-9 or M12), center
- Ethernet port (RJ45, shielded), center
- Status LEDs (Power, Fault, CAN Activity), right of center
- Extraction handle with latch mechanism, right side

**Rear panel (455 × 94 mm):**
- DC output studs (M8, + / − / PE), center
- Fan exhaust grille (perforated, 60% open area), full width
- PE bonding stud (M6), bottom corner

**Top panel (455 × 300 mm):**
- Ventilation slots (IP20): 3 mm wide × 30 mm long, staggered pattern, ≥40% open area over heatsink region
- Removable cover secured by 4× M3 captive screws (for board access)

**Bottom panel (455 × 300 mm):**
- Intake ventilation slots (IP20), same pattern as top
- Rack slide rail mounting points, 4× M4 tapped holes per side

### 2.4 Rack Slide Rails

- Type: Telescoping ball-bearing slides, 300 mm travel
- Load rating: ≥25 kg per pair (provides margin for 17 kg module)
- Hot-swap: module slides out for service; blind-mate DC connector at rear engages automatically on insertion
- Latch: front panel latch locks module in operating position; lever releases for extraction
- Guide pins: 2× tapered guide pins on rear panel align module to backplane before electrical contact

---

## 3. Internal Layout and Board Arrangement

### 3.1 Top-Down Layout Diagram

```
┌─────────────────────────────────────────────────────────────┐
│ FRONT PANEL  [AC IN]  [CAN] [ETH] [LEDs]  [HANDLE/LATCH]    │
├─────────────────────────────────────────────────────────────┤
│                                                             │
│  ┌──────────────────────┐    ┌──────────────────────┐       │
│  │                      │    │                      │       │
│  │     AC-DC Board      │    │     DC-DC Board      │       │
│  │     250 × 180 mm     │ P2 │     250 × 180 mm     │       │
│  │                      │◄──►│                      │       │
│  │  [EMI]  [PFC]  [Caps]│bus │ [Pri] [Xfmr] [Sec]   │       │
│  │                      │bar │                      │       │
│  └──────────┬───────────┘    └──────────┬───────────┘       │
│             │                           │                   │
│       ┌─────┴──────┐  ┌────────────┐    │  output bus bar   │
│       │  Aux PSU   │  │ Controller │    │  to rear panel    │
│       │  100 × 80  │  │ 120 × 100  │    ▼                   │
│       └────────────┘  └────────────┘  [DC OUT STUDS]        │
│                                                             │
│                     ◄── AIRFLOW DIRECTION ──►               │
│                                                             │
│  ┌────────────────────────────────────────────────────────┐ │
│  │            FAN ZONE  (80mm × 2 or 120mm × 1)           │ │
│  └────────────────────────────────────────────────────────┘ │
├─────────────────────────────────────────────────────────────┤
│ REAR PANEL      [DC+] [DC−] [PE]     [FAN EXHAUST GRILLE]   │
└─────────────────────────────────────────────────────────────┘
```

### 3.2 Side Profile (Cross-Section)

```
          ◄─── 300 mm (depth) ──►
    ┌─────────────────────────────┐ ─┬─
    │  TOP COVER (removable)      │  │
    ├─────────────────────────────┤  │
    │  PCB components (top side)  │  │
    │  ─ ─ ─ ─ PCB ─ ─ ─ ─ ─ ─  │  │ 94 mm
    │  MOSFET tabs ↓              │  │
    │  ═══ TIM (0.25 mm) ═══════ │  │
    │  ▓▓▓ HEATSINK BASE (8mm) ▓ │  │
    │  ║║║║ FINS (35 mm) ║║║║║║║ │  │
    ├─────────────────────────────┤  │
    │  BASEPLATE                  │  │
    └─────────────────────────────┘ ─┴─
```

### 3.3 Board Placement Rules

| Rule | Specification |
|---|---|
| AC-DC board position | Left side, adjacent to AC input connector |
| DC-DC board position | Right side, adjacent to DC output studs |
| Controller board position | Bottom-center, below power boards, shielded from power stage EMI |
| Aux PSU position | Bottom-left, between AC-DC and controller, close to gate drive outputs |
| Board-to-board clearance | ≥ 10 mm vertical, ≥ 5 mm horizontal (airflow channels) |
| Signal harness routing | Along enclosure side walls, physically separated ≥ 15 mm from bus bars |
| Creepage (AC-DC to enclosure) | ≥ 8 mm (per IEC 62109-1 for 530 VAC working voltage) |
| Creepage (DC bus to enclosure) | ≥ 10 mm (920 VDC bus) |

### 3.4 Airflow Path

The airflow path is designed as a single front-to-rear pass:

1. **Intake** — air enters through bottom and front ventilation slots, passes through removable dust filter
2. **EMI filter section** — low-loss components, air pre-heats minimally (~2–3°C)
3. **PFC MOSFETs and boost inductors** — primary heat source on AC-DC board, heatsink fins below
4. **DC bus capacitors** — moderate heating, benefits from airflow
5. **LLC primary MOSFETs** — second major heat source on DC-DC board
6. **Transformer and output rectifiers** — remaining losses on DC-DC board
7. **Exhaust fans** — pull air through the entire heatsink fin field and exhaust through rear grille

> [!warning] Do not reverse the airflow direction
> The EMI filter components have the lowest thermal sensitivity and should receive the coolest air. Reversing the flow would expose the most temperature-sensitive components (SiC MOSFETs) to pre-heated air from the transformer, reducing thermal margin.

---

## 4. Heatsink Design

### 4.1 Heatsink Geometry

| Parameter | Value |
|---|---|
| Type | Extruded aluminum, single piece |
| Material | 6063-T5 (k = 201 W/m·K) |
| Overall length | 455 mm (spans both AC-DC and DC-DC boards) |
| Width | 180 mm (matches board width) |
| Base thickness | 8 mm |
| Fin height | 35 mm |
| Fin thickness | 1.5 mm |
| Fin pitch | 3.5 mm (center-to-center) |
| Number of fins | ~50 |
| Fin efficiency (forced air, 2.5 m/s) | ~82% |
| Total surface area | ~0.85 m² |
| Mass | ~3.2 kg |

### 4.2 Heatsink Configuration Options

**Option A — Single Continuous Heatsink (recommended):**

- One extrusion spans the full 455 mm enclosure width
- Both AC-DC and DC-DC boards mount to the same heatsink
- Advantages: better thermal spreading between boards, simpler assembly, fewer parts
- Disadvantage: replacing one board requires partial disassembly of the other board's mounting

**Option B — Dual Separate Heatsinks:**

- Two extrusions, each ~220 mm long, with a 15 mm gap between them
- Each board has its own thermally independent heatsink
- Advantage: easier single-board replacement
- Disadvantage: no thermal cross-coupling benefit, slightly higher total Rth_sa

> [!note] Recommendation
> Option A (single heatsink) is selected as the baseline. The thermal spreading benefit is worth ~5°C at the hottest MOSFET, which directly translates to extended derating headroom. Board replacement is infrequent enough that the minor disassembly penalty is acceptable.

### 4.3 Thermal Interface Material (TIM)

| Property | Specification |
|---|---|
| Material | Bergquist Gap Pad GP3000S30 (or equivalent) |
| Thermal conductivity | 3.0 W/m·K |
| Thickness | 0.25 mm (compressed) |
| Compressive force | 50–100 psi at rated thickness |
| Operating temperature | −40°C to +200°C |
| Dielectric breakdown | 10 kV/mm (2.5 kV at 0.25 mm) |

Alternative: Shin-Etsu MicroSi TC-30AG thermal grease (4.3 W/m·K) for lower Rth_cs but requires careful dispensing control during assembly.

### 4.4 Thermal Resistance Budget

Per MOSFET device (e.g., C3M0032120K in TO-247-4):

| Thermal Path | Symbol | Value (°C/W) | Notes |
|---|---|---|---|
| Junction to case | Rth_jc | 0.50 | Datasheet maximum |
| Case to heatsink | Rth_cs | 0.12 | GP3000S, 0.25 mm, 1.3 cm² contact |
| Heatsink to ambient | Rth_sa | 0.35 | Forced air 2.5 m/s, per device footprint |
| **Junction to ambient** | **Rth_ja** | **0.97** | **Total** |

**Temperature check at worst case (55°C ambient, single MOSFET dissipating 40 W):**

```
T_junction = T_ambient + (P_diss × Rth_ja)
T_junction = 55 + (40 × 0.97) = 93.8°C
```

This provides 81°C margin to the 175°C SiC junction limit, or 56°C margin to the 150°C design target.

### 4.5 Heatsink Mounting

- MOSFET packages (TO-247-4, HiP247) are screwed directly through the PCB mounting hole into tapped M3 holes in the heatsink base
- Screw: M3 × 8 mm pan-head, zinc-plated steel
- Washer: Belleville spring washer (maintains clamp force under thermal cycling)
- Torque: 0.4–0.5 N·m
- Additional PCB support: 4× M3 standoffs at board corners, 8 mm height, brass (nickel-plated), tapped into heatsink

> [!warning] Torque control is critical
> Under-torquing increases Rth_cs and risks thermal runaway. Over-torquing can crack the ceramic substrate in insulated packages or deform the PCB. Use a calibrated torque screwdriver during assembly.

---

## 5. Fan System

### 5.1 Fan Configuration

The baseline design uses two 80 mm axial fans in a push-pull arrangement at the rear of the enclosure:

| Parameter | Specification |
|---|---|
| Configuration | 2× 80 mm axial fans, exhaust (pull) |
| Arrangement | Side-by-side, covering full heatsink width |
| Total airflow required | ≥ 55 CFM (at system impedance) |
| System impedance | ~7 mm H₂O at 55 CFM |
| Voltage | 12 VDC (from Aux PSU board) |
| Speed control | PWM, 25 kHz, duty range 20–100% |
| Tachometer output | Open-drain pulse, 2 pulses/revolution |
| Bearing type | Dual ball bearing (rated ≥70,000 hours at 60°C) |

### 5.2 Fan Candidates

| Model | Size | Max CFM | Max Pressure | Noise (max) | Current | MTBF |
|---|---|---|---|---|---|---|
| Sanyo Denki 9GA0812P4G01 | 80×25 mm | 67.9 CFM | 11.2 mm H₂O | 52 dBA | 0.58 A | 70k hr |
| Delta FFB0812EH | 80×25 mm | 57.2 CFM | 9.1 mm H₂O | 50 dBA | 0.51 A | 70k hr |
| Sunon MF80252V1-1000U-A99 | 80×25 mm | 62.0 CFM | 8.5 mm H₂O | 45 dBA | 0.42 A | 70k hr |
| NMB 3115RL-04W-B86 | 80×25 mm | 55.0 CFM | 7.8 mm H₂O | 43 dBA | 0.65 A | 100k hr |

> [!tip] Fan selection
> The Sanyo Denki 9GA0812P4G01 is the baseline selection due to its high static pressure (11.2 mm H₂O) which provides margin against heatsink fin resistance. At 70% PWM duty the noise target of < 55 dB is met while still delivering > 40 CFM per fan.

### 5.3 Noise Budget

| Condition | Fan Duty | Airflow (total) | Noise |
|---|---|---|---|
| Light load (< 15 kW, T_amb ≤ 35°C) | 30% | ~25 CFM | < 35 dBA |
| Half load (15 kW, T_amb ≤ 45°C) | 50% | ~40 CFM | < 45 dBA |
| Full load (30 kW, T_amb ≤ 45°C) | 70% | ~55 CFM | < 55 dBA |
| Full load, high ambient (30 kW, T_amb = 55°C) | 100% | ~68 CFM | < 63 dBA |
| Emergency derating | 100% | ~68 CFM | < 63 dBA |

### 5.4 Fan Speed Control Algorithm

The controller board reads heatsink temperature via NTC thermistors (one per power board, bonded to heatsink base) and applies a piecewise-linear fan curve:

```
Heatsink Temp (°C)    Fan PWM Duty (%)
───────────────────   ─────────────────
      ≤ 40                  20  (minimum)
       50                   40
       60                   60
       70                   80
      ≥ 75                 100
      ≥ 90            FAULT → OTP shutdown
```

Fan tachometer feedback is monitored continuously. If either fan reports < 500 RPM while commanded > 30% duty, the controller asserts a fan-fail warning and begins power derating per [[09-Protection and Safety]].

### 5.5 Fan Mounting

- Fans are mounted to an internal bracket (1.2 mm aluminum) using 4× M4 screws with silicone rubber grommets at each mounting point
- Grommets decouple fan vibration from the enclosure, reducing structure-borne noise by ~5 dBA
- Fan bracket is secured to the enclosure rear panel with 4× M3 screws
- Wire routing: fan power/PWM/tach cables routed along the enclosure side wall to the Aux PSU and Controller boards respectively

### 5.6 Dust Filter

- Location: intake side (bottom panel, IP20 configuration)
- Media: polyester mesh, 45 PPI (pores per inch), ~80% open area
- Frame: snap-in plastic frame, tool-free removal for cleaning
- Replacement interval: every 6 months (or as indicated by pressure differential)
- Pressure drop (clean): < 0.5 mm H₂O
- Pressure drop (dirty, replacement threshold): 2.0 mm H₂O

---

## 6. Bus Bar Design

### 6.1 P2 DC Bus Bar (AC-DC → DC-DC)

The P2 bus bar carries the full DC bus current (~35 A at 30 kW, 920 VDC) between the AC-DC board output capacitors and the DC-DC board primary input.

| Parameter | Specification |
|---|---|
| Type | Laminated bus bar pair (DC_BUS+ / DC_BUS−) |
| Material | Electrolytic copper, C11000, tin-plated (3–5 µm) |
| Conductor thickness | 2.0 mm per layer |
| Conductor width | 25 mm |
| Insulation | Kapton HN polyimide film, 0.2 mm (rated 7 kV/mm) |
| Total stack height | 2.0 + 0.2 + 2.0 = 4.2 mm |
| Length | 65 mm (center-to-center, board gap) |
| DC resistance | < 0.15 mΩ |
| Inductance | ≤ 3 nH (laminated pair, < 5 nH target) |
| Current rating | 40 A continuous (< 20°C rise in still air) |
| Voltage rating | 1000 VDC (working), 2500 VDC (hipot test) |
| Mounting | M4 hex-flange bolts, 2 per end |
| Torque | 1.0–1.2 N·m |

```
CROSS-SECTION (P2 BUS BAR):

    ┌────────────────────────┐
    │  DC_BUS+ (Cu, 2 mm)   │  ← bolts to AC-DC board pad
    ├════════════════════════┤
    │  Kapton (0.2 mm)       │  ← dielectric insulation
    ├════════════════════════┤
    │  DC_BUS− (Cu, 2 mm)   │  ← bolts to AC-DC board pad
    └────────────────────────┘
    ◄──────── 25 mm ────────►
```

> [!warning] Laminated bus bar parasitic inductance
> The low inductance of the laminated bus bar is critical to limiting voltage overshoot during MOSFET switching on the DC-DC primary side. If the bus bar inductance exceeds 5 nH, the voltage spike at turn-off (with 35 A, 50 ns di/dt) reaches V_spike = L × di/dt ≈ 5 nH × 700 A/µs = 3.5 V — manageable, but larger inductance values compound with PCB trace inductance and can cause ringing above the 1200 V device rating.

### 6.2 Output Bus Bar (DC-DC → Rear Panel)

| Parameter | Specification |
|---|---|
| Rating | 100 A continuous |
| Material | Copper, C11000, tin-plated |
| Thickness | 3.0 mm |
| Width | 30 mm |
| Length | ~100 mm (DC-DC board edge to rear panel studs) |
| DC resistance | < 0.10 mΩ |
| Current density | < 3.3 A/mm² (< 25°C rise) |
| Insulation | Kapton sleeve or heat-shrink, rated 1000 VDC |
| Mounting (board side) | M5 bolts to PCB bus bar pads, 1.5 N·m |
| Mounting (panel side) | M8 studs through rear panel, insulating bushings |

Two bars are required: DC_OUT+ and DC_OUT−. A third PE bar or braid bonds the DC output ground reference to the enclosure PE stud.

### 6.3 AC Input Interconnect

| Parameter | Specification |
|---|---|
| Type | Individual wires or flat bus bars, 3 phases + neutral + PE |
| Wire gauge (if wired) | 10 AWG (5.26 mm²) minimum per phase, silicone insulated, rated 600 V |
| Bus bar option | 1.5 mm copper, 15 mm wide per phase, insulated |
| Length | ~200 mm (front panel connector to AC-DC board edge) |
| Termination (panel side) | Ring terminals or direct bolted to input connector studs |
| Termination (board side) | Soldered or bolted to PCB input pads |

---

## 7. Connector Specifications

### 7.1 External Connectors

| ID | Connector | Type | Rating | Location | Mating Cycles |
|----|---|---|---|---|---|
| J1 | AC Input (L1/L2/L3/N/PE) | Phoenix COMBICON GMSTBA 2.5/5-ST or M6 studs | 530 VAC, 60 A | Front panel | 100+ (studs) |
| J2 | DC Output (+) | M8 stud, flanged, insulated bushing | 1000 VDC, 100 A | Rear panel | 500 (blind-mate option) |
| J3 | DC Output (−) | M8 stud, flanged, insulated bushing | 1000 VDC, 100 A | Rear panel | 500 |
| J4 | PE Output | M6 stud, direct bonded to enclosure | — | Rear panel | — |
| J5 | CAN Bus | DB-9 male (CANopen pinout) or M12-A 5-pin | 1 Mbps, 5 VDC | Front panel | 500 |
| J6 | Ethernet (OCPP) | RJ45, shielded, Cat5e | 100 Mbps | Front panel | 750 |

### 7.2 Internal Connectors (Board-to-Board)

| ID | Connector | Mating Pair | Rating | From → To |
|----|---|---|---|---|
| P2 | Bus bar (bolted) | M4 bolted pads | 920 VDC, 40 A | AC-DC → DC-DC |
| P4 | Molex Micro-Fit 3.0, 8-pin (43025-0800) | 43020-0801 | 18 VDC, 0.5 A/pin | Aux PSU → AC-DC & DC-DC gate drives |
| P5 | Molex Micro-Fit 3.0, 4-pin (43025-0400) | 43020-0401 | 5 VDC, 1 A/pin | Aux PSU → Controller board |
| S1 | Molex Pico-Lock 12-pin (504050-1200) | 504051-1201 | 3.3 V signal, 50 mA | Controller → AC-DC (PFC PWM, ADC, fault) |
| S2 | Molex Pico-Lock 10-pin (504050-1000) | 504051-1001 | 3.3 V signal, 50 mA | Controller → DC-DC (LLC PWM, ADC, fault) |
| F1 | JST PH 2-pin (B2B-PH-K-S) | PHR-2 | 12 VDC, 0.6 A | Aux PSU → Fan 1 power |
| F2 | JST PH 2-pin (B2B-PH-K-S) | PHR-2 | 12 VDC, 0.6 A | Aux PSU → Fan 2 power |
| F3 | JST PH 4-pin (B4B-PH-K-S) | PHR-4 | 5 V signal | Controller → Fan PWM & tach (2× fans) |
| T1 | JST PH 2-pin | PHR-2 | NTC signal | Heatsink NTC 1 → Controller ADC |
| T2 | JST PH 2-pin | PHR-2 | NTC signal | Heatsink NTC 2 → Controller ADC |

### 7.3 Connector Placement Rules

- High-voltage connectors (P2, J1, J2, J3): minimum 10 mm creepage to enclosure and to any signal connector
- Signal harnesses (S1, S2, F3, T1, T2): routed in a dedicated channel along the enclosure side wall, separated ≥ 15 mm from any power conductor
- Power harnesses (P4, P5): routed between Aux PSU and power boards, twisted pair where possible to reduce EMI
- All connectors must be keyed or polarized to prevent mis-mating
- Locking/latching connectors required for all harnesses subject to vibration (Micro-Fit 3.0 and Pico-Lock both have latches)

---

## 8. Board Mounting and Standoffs

### 8.1 Mounting Summary

| Board | Mount Surface | Standoff Height | Standoff Type | Fastener | Count |
|---|---|---|---|---|---|
| AC-DC | Heatsink | 0 mm (direct via MOSFET screws) + 8 mm corner standoffs | Brass, M3, nickel-plated | M3 × 8 pan-head + Belleville | 6 MOSFET + 4 corner |
| DC-DC | Heatsink | 0 mm (direct via MOSFET screws) + 8 mm corner standoffs | Brass, M3, nickel-plated | M3 × 8 pan-head + Belleville | 6 MOSFET + 4 corner |
| Controller | Enclosure floor | 8 mm | Nylon, M3 (isolated from chassis ground) | M3 × 6 nylon screw | 4 corner |
| Aux PSU | Enclosure floor | 6 mm | Brass, M3, nickel-plated | M3 × 6 pan-head | 4 corner |

> [!note] Controller board isolation
> The Controller board uses nylon standoffs to prevent ground loops between the digital ground plane and the chassis/power ground. A single-point chassis connection is made via a dedicated grounding pad on the Controller PCB, bonded to the enclosure with a short braid.

### 8.2 Standoff Details

**Brass standoffs (power boards and Aux PSU):**

| Dimension | Value |
|---|---|
| Thread | M3 × 0.5, female-female |
| Length | 6 mm (Aux PSU) or 8 mm (power boards) |
| Material | CDA 360 brass, nickel-plated |
| Hex width | 5.5 mm across flats |
| Mounting to heatsink/chassis | M3 × 5 mm flat-head screw from below |

**Nylon standoffs (Controller board):**

| Dimension | Value |
|---|---|
| Thread | M3 × 0.5, female-female |
| Length | 8 mm |
| Material | Nylon 6/6, UL94 V-2 rated |
| Hex width | 5.5 mm across flats |
| Temperature rating | −40°C to +85°C |

### 8.3 Vibration and Shock Requirements

Per IEC 60068-2-6 and IEC 60068-2-27 (referenced by IEC 61851-23 for EV charging equipment):

| Test | Specification |
|---|---|
| Sinusoidal vibration | 10–150 Hz, 2g peak, 2 hours per axis (3 axes) |
| Mechanical shock | 30g, 11 ms half-sine, 3 shocks per direction (18 total) |
| Random vibration (transport) | 5–200 Hz, 1.5 grms, 30 min per axis |

Design features for vibration resistance:

- All screws use spring washers (Belleville for MOSFET screws, split lock for standoffs) or thread-locking compound (Loctite 243, medium strength)
- PCB mass is supported at ≥ 4 points, limiting maximum unsupported span to < 80 mm
- Heavy components (inductors, transformers) have supplemental adhesive bonding (Dow Corning 3145 RTV) to PCB in addition to solder joints
- Fan mounting uses silicone rubber grommets to decouple vibration
- Wire harnesses have strain relief at both connector ends and tie-down points every 50 mm along the routing path

---

## 9. Thermal Derating and Airflow Validation

### 9.1 CFD Simulation Targets

| Parameter | Target | Limit |
|---|---|---|
| Max heatsink surface temp (at hottest MOSFET) | < 85°C at 55°C ambient, full load | 95°C absolute max |
| Max MOSFET junction temp | < 150°C | 175°C (device rating) |
| Max transformer hotspot | < 130°C | 155°C (Class F insulation) |
| Max DC bus capacitor temp | < 85°C | 105°C (rated life) |
| Airflow velocity over fins | ≥ 2.0 m/s | 1.5 m/s minimum |
| Total enclosure pressure drop | < 10 mm H₂O | 12 mm H₂O (fan stall margin) |
| Air temperature rise (inlet to outlet) | < 25°C | 30°C |

### 9.2 Thermal Derating Table

| Ambient Temp (°C) | Max Output Power (kW) | % of Rated | Fan Speed (%) | Heatsink Temp (°C) | T_j Estimate (°C) |
|---|---|---|---|---|---|
| ≤ 35 | 30.0 | 100% | 30–50 | ≤ 60 | ≤ 100 |
| 40 | 30.0 | 100% | 50–60 | ≤ 70 | ≤ 110 |
| 45 | 30.0 | 100% | 60–80 | ≤ 80 | ≤ 120 |
| 50 | 25.0 | 83% | 80–90 | ≤ 82 | ≤ 130 |
| 55 | 20.0 | 67% | 100 | ≤ 85 | ≤ 140 |
| 60 | 15.0 | 50% | 100 | ≤ 85 | ≤ 140 |
| 65 | 0 (shutdown) | 0% | 100 → off | — | — |

> [!tip] Derating is applied gradually
> The controller implements a continuous derating curve (not step changes) by reducing the maximum current command proportionally as heatsink temperature rises above the 75°C threshold. This avoids abrupt power transients during charging sessions. See [[09-Protection and Safety]] for OTP threshold definitions.

### 9.3 Airflow Resistance Estimate

```
Component              Pressure Drop (mm H₂O)
─────────────────────  ──────────────────────
Dust filter (clean)           0.5
Intake grille                 0.3
Heatsink fins (50 fins,       5.5
  35 mm tall, 3.5 mm pitch,
  455 mm long, at 2.5 m/s)
PCB obstructions              0.5
Exhaust grille                0.3
──────────────────────────────────
Total system impedance        7.1 mm H₂O
```

At 7.1 mm H₂O, the Sanyo Denki 9GA0812P4G01 (2× fans in parallel) delivers approximately 55 CFM, which is sufficient for the ~1 kW dissipation budget.

---

## 10. EMC Enclosure Considerations

### 10.1 Shielding Effectiveness Targets

| Frequency Range | Target SE | Method |
|---|---|---|
| 150 kHz – 30 MHz (conducted) | N/A (handled by EMI filter) | — |
| 30 MHz – 200 MHz | ≥ 40 dB | Panel joint continuity, gaskets |
| 200 MHz – 1 GHz | ≥ 30 dB | Slot control, waveguide vents |
| > 1 GHz | ≥ 20 dB | Aperture size control |

### 10.2 Panel Joint Design

- All panel edges have continuous conductive contact via one of:
  - Finger stock gasket (BeCu, tin-plated) on removable covers
  - Conductive EMI gasket (Chomerics CHO-SEAL 1285) on permanent joints
  - Direct metal-to-metal contact with chromate-coated mating surfaces (screw spacing ≤ 30 mm)
- Maximum slot length at any panel joint: < 15 mm (λ/4 at 5 GHz)
- Screw spacing along panel joints: ≤ 30 mm for panels, ≤ 50 mm for non-critical covers

### 10.3 Cable Entry EMC

| Entry Point | EMC Treatment |
|---|---|
| AC input (J1) | Shielded cable, shield terminated 360° at panel bulkhead via EMC cable gland |
| DC output (J2/J3) | Studs with insulated bushings; cable shield bonded to PE stud at panel exit |
| CAN bus (J5) | Shielded DB-9 with conductive backshell bonded to panel |
| Ethernet (J6) | Shielded RJ45 jack with integrated common-mode choke, shell bonded to panel |
| Fan wires (internal) | Ferrite bead on each fan wire pair, placed within 20 mm of board connector |

### 10.4 Ventilation EMC

For IP20 ventilation slots to maintain shielding effectiveness:

- Slot geometry: 3 mm wide × 30 mm long (waveguide below cutoff above ~5 GHz)
- Slots oriented perpendicular to longest enclosure dimension
- For frequencies below 1 GHz: slot length must be < 75 mm (λ/4 at 1 GHz); the 30 mm slots satisfy this
- Optional: honeycomb EMI filter panels (cell size 3 mm, depth 10 mm) for applications requiring > 40 dB SE at high frequencies

### 10.5 Internal Partitioning

An optional internal EMC shield (0.5 mm aluminum sheet) can be installed between the power section (AC-DC and DC-DC boards) and the control section (Controller and Aux PSU boards):

- Shield is bonded to enclosure at ≥ 4 points
- Pass-through holes for signal harnesses (S1, S2) use ferrite-lined grommets
- Pass-through holes for power harnesses (P4, P5) use feedthrough capacitors or ferrite beads

---

## 11. Assembly Sequence
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

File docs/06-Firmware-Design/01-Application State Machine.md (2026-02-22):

---
tags: [PDU, firmware, state-machine, STM32G474, implementation]
created: 2026-02-22
---

# 01 – Application State Machine

> [!note] Scope
> This document defines the top-level application state machine for the 30 kW PDU firmware. For HRTIM resource mapping, ADC allocation, and control loop structures, see [[06-Firmware Architecture]]. For HW-side power-on sequencing (NTC, relay, contactor), see [[08-Power-On Sequence and Inrush Management]].

---

## 1. State Enumeration

The application runs a single top-level state machine (`AppState_t`) in the main loop at 1 kHz. All ISR-level control loops (PFC current, LLC voltage) check `g_app_state` to decide whether to produce active PWM output.
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

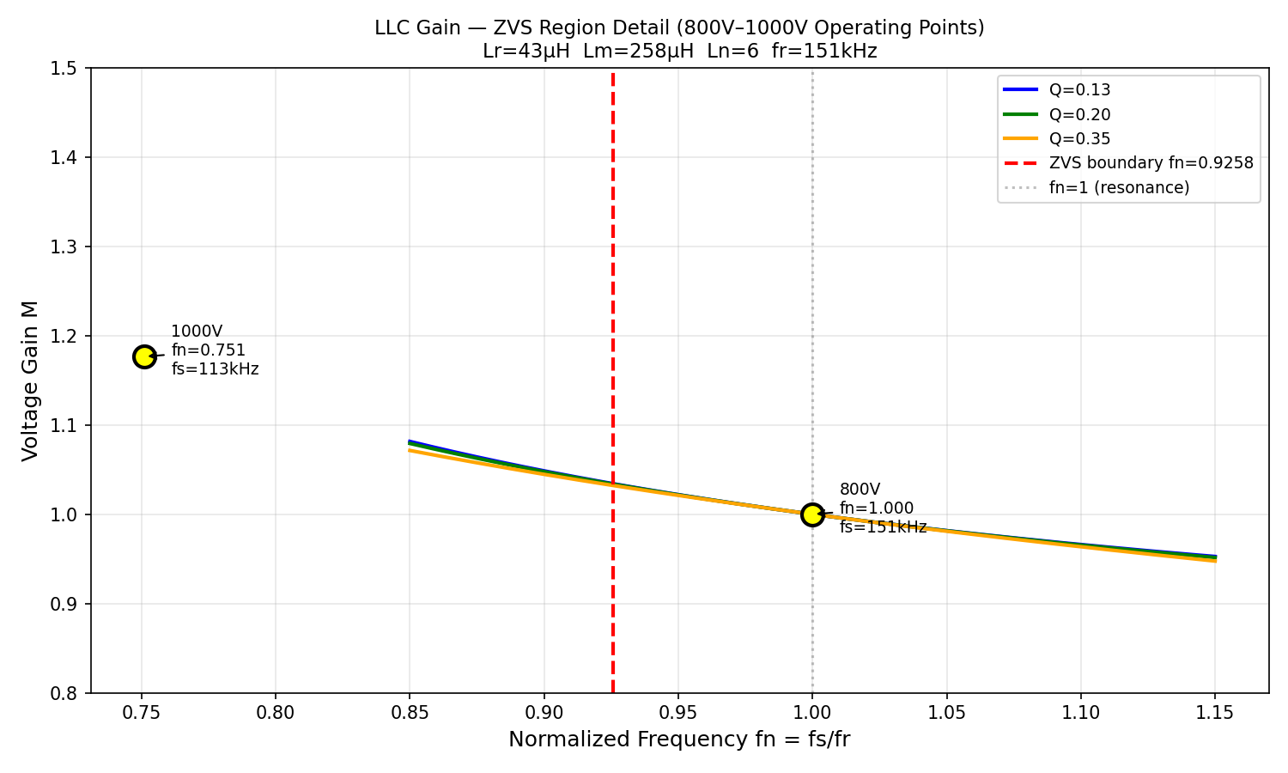
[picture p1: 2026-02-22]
sim/llc_zvs_detail.png

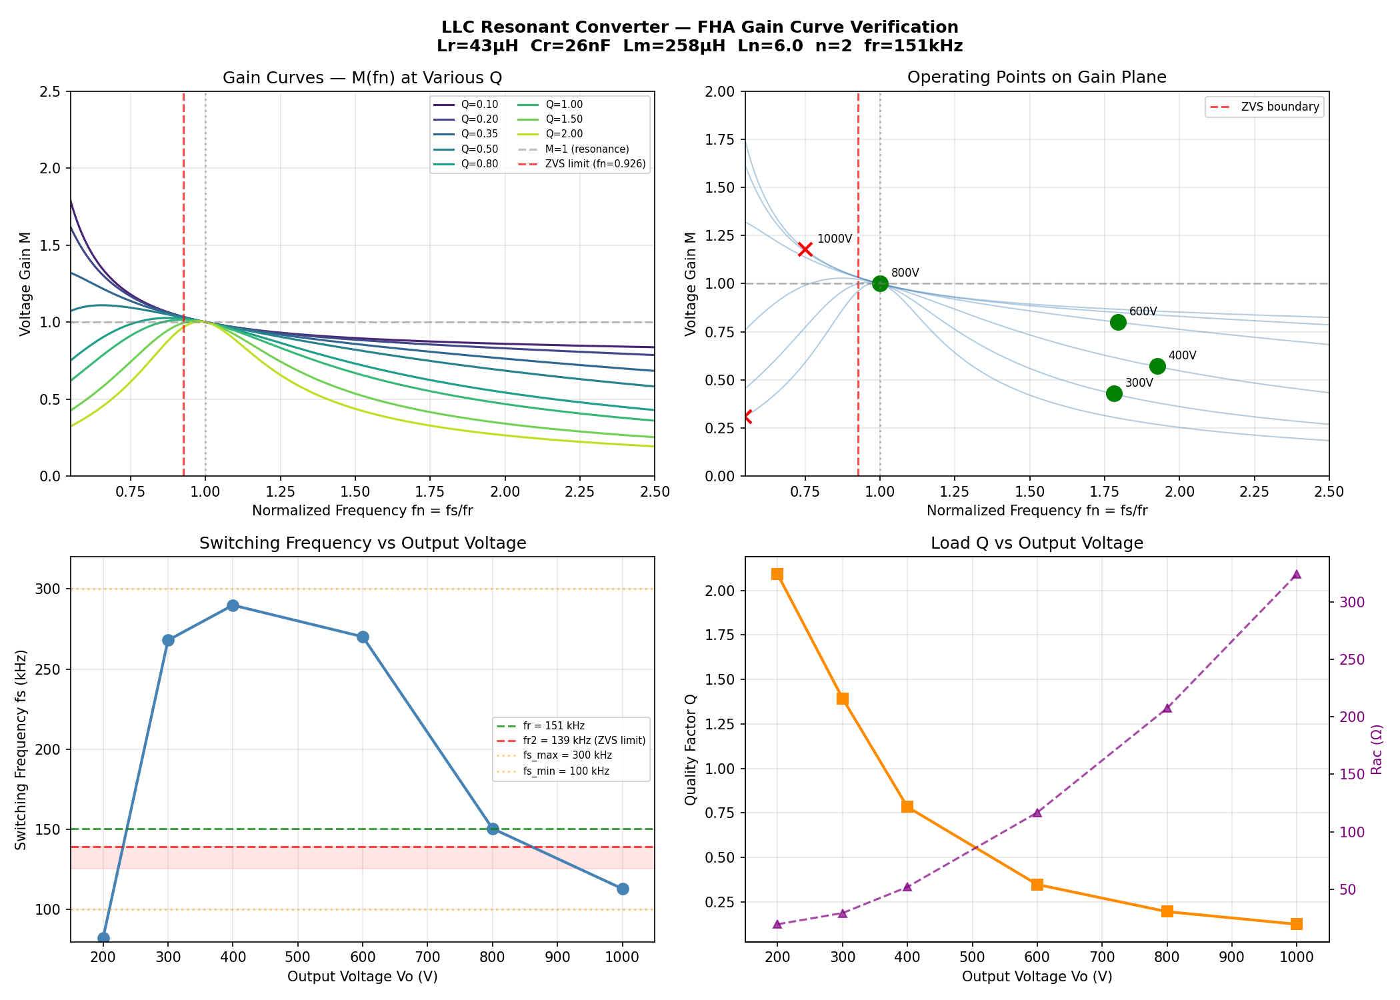
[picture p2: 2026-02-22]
sim/llc_gain_curves.png

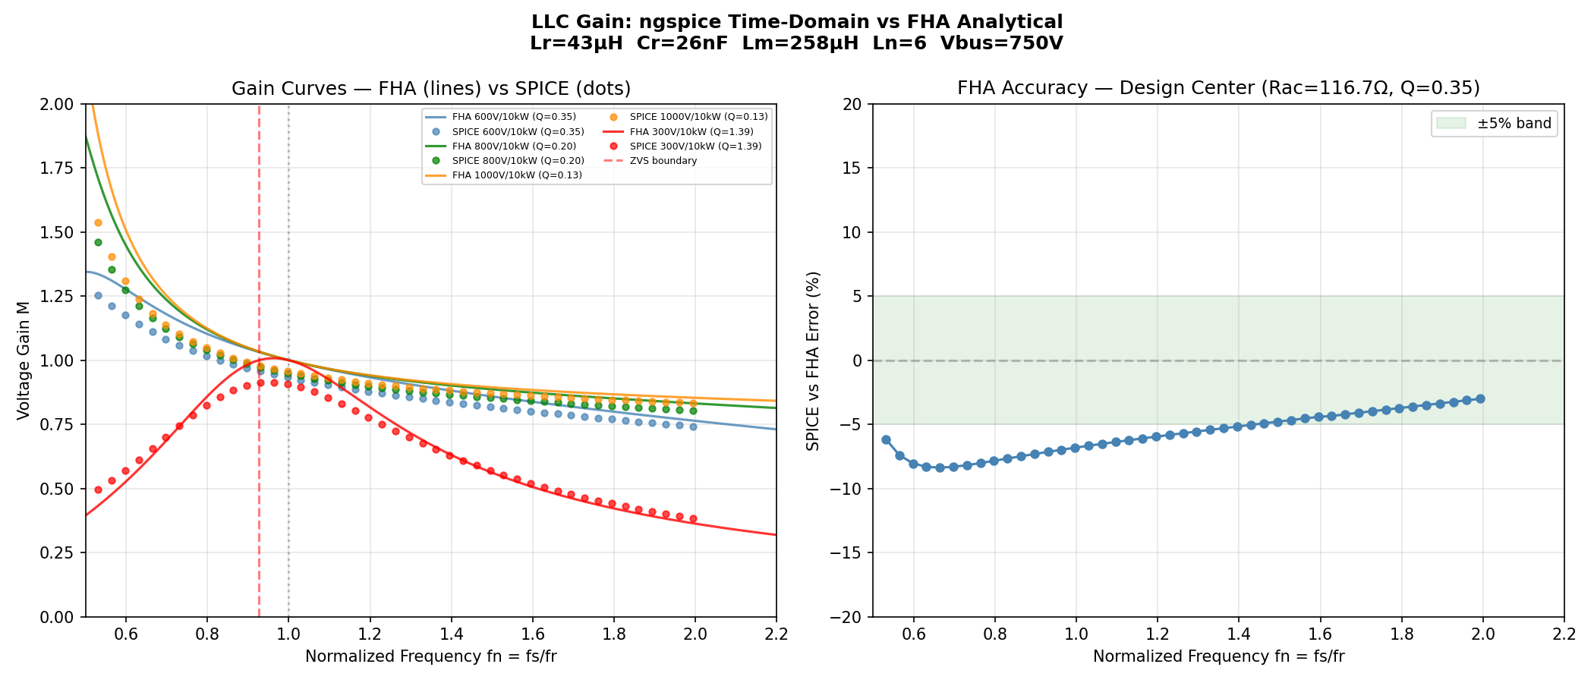
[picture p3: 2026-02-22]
sim/llc_spice_vs_fha.png

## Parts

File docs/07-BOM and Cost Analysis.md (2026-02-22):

---
tags: [PDU, BOM, cost-analysis, procurement, SiC, EV-charging]
created: 2026-02-22
status: draft
---

# BOM and Cost Analysis — 30 kW PDU

> [!summary] Key Results
> Per-module BOM cost: **~$1,726 @qty 100** (production pilot), **~$1,383 @qty 500** (volume). Semiconductors (SiC + ICs) dominate at 35% of total. Five-module 150 kW system: ~$9,279 @100, ~$7,434 @500. Primary cost reduction levers: Chinese SiC alternates (-20-30%), nanocrystalline core sourcing (-40%), and resonant capacitor optimization (-50%).

## 1. Scope and Assumptions

This document consolidates every component specified across the six design documents ([[01-Topology Selection]], [[02-Magnetics Design]], [[03-LLC Gain Curve Verification]], [[04-Thermal Budget]], [[05-EMI Filter Design]], [[06-Firmware Architecture]]) into a single costed bill of materials.

| Assumption | Value |
|---|---|
| Pricing basis | Per-module (single 30 kW unit) |
| Quantity tiers | @100 modules (production pilot), @500 modules (volume) |
| Currency | USD, 2025-2026 distributor/contract pricing |
| Semiconductor sourcing | US/EU authorized distributors (Mouser, Digi-Key, Arrow) |
| Passive/mechanical sourcing | Mix of distributor and China-sourced mechanical |
| Excludes | Test fixtures, development tools, certification costs, NRE tooling (noted separately) |

## 2. Semiconductor BOM

### 2.1 Power Semiconductors

| Part Number | Function | Package | Qty | Unit @100 | Unit @500 | Extended @100 | Source Doc |
|---|---|---|-----|---|---|---|---|
| SCTWA90N65G2V-4 | PFC SiC MOSFET, 650 V 22 mΩ | HiP247-4 | 6 | $24.00 | $20.00 | $144.00 | [[01-Topology Selection]] §3.3 |
| STPSC40H12C | PFC SiC Schottky diode, 1200 V 40 A | TO-247 LL | 12 | $11.00 | $9.00 | $132.00 | [[01-Topology Selection]] §3.3 |
| SCTW100N120G2AG | LLC primary SiC MOSFET, 1200 V 36 mΩ | HiP247 | 6 | $40.00 | $32.00 | $240.00 | [[01-Topology Selection]] §4.3, [[04-Thermal Budget]] §2.2 |
| STPSC20H065CW | LLC secondary SiC Schottky, 650 V 2×10 A | TO-247 | 9 | $6.50 | $5.00 | $58.50 | [[01-Topology Selection]] §4.3, [[04-Thermal Budget]] §2.2 |

**Power semiconductor subtotal: $574.50 @100, $462.00 @500**

> [!note] LLC secondary diode quantity
> 9 diodes: 3 per LLC phase (center-tapped secondary with 2 diodes + 1 spare position). Actual population depends on output voltage range requirement. At full output range (150–1000 V), all 9 positions populated.

### 2.2 Gate Drivers and ICs

| Part Number | Function | Package | Qty | Unit @100 | Unit @500 | Extended @100 | Source Doc |
|---|---|---|-----|---|---|---|---|
| STGAP2SiC | Isolated gate driver, SiC-optimized | SO-8W | 6 | $3.00 | $2.60 | $18.00 | [[01-Topology Selection]] §5 |
| STM32G474RE | MCU, Cortex-M4F 170 MHz, HRTIM | LQFP-64 | 1 | $6.50 | $5.00 | $6.50 | [[06-Firmware Architecture]] §1 |
| SN65HVD230 | CAN 2.0 transceiver | SOIC-8 | 1 | $1.60 | $1.30 | $1.60 | [[06-Firmware Architecture]] §6.1 |

**IC subtotal: $26.10 @100, $21.30 @500**

### 2.3 Semiconductor Summary

| Category | @100 | @500 |
|---|---|---|
| Power semiconductors | $574.50 | $462.00 |
| Gate drivers + ICs | $26.10 | $21.30 |
| **Semiconductor total** | **$600.60** | **$483.30** |

## 3. Magnetics BOM (×3 Phases)

All magnetics values from [[02-Magnetics Design]] §8.

### 3.1 Per-Phase Components

| Component | Part / Specification | Qty/Phase | Unit Cost @100 | Notes |
|---|---|---|---|---|
| Transformer core set | E65/32/27, 3C97 (Ferroxcube) | 1 set | $14.00 | Core pair + clamp |
| Transformer bobbin | B65/32 (Ferroxcube) with pin header | 1 | $3.00 | |
| Primary winding wire | Litz 44 AWG × 800 strands, 21 turns | ~8 m | $16.00 | ~$2.00/m |
| Secondary winding wire | Litz 44 AWG × 400 strands, 42 turns | ~12 m | $14.40 | ~$1.20/m |
| Kapton interlayer insulation | 0.05 mm × 25 mm, 3 layers | 1 set | $1.50 | 5 kV isolation class |
| Core clamp / mounting | Spring clip or adhesive bracket | 1 | $1.00 | |
| Resonant inductor core | Kool Mu 77439 toroid, µ=60 (Magnetics Inc.) | 1 | $7.50 | 33 µH discrete Lr |
| Resonant inductor winding | Litz 44 AWG × 400 strands, 24 turns | ~3 m | $3.60 | |
| Resonant capacitor | TDK CGA9N4C0G2J103J, 10 nF 630 V C0G 2220 | 24 | $24.00 | 8P × 3S = 26.7 nF, $1.00 each |

**Per-phase magnetics cost: ~$85.00 @100**

### 3.2 Magnetics Summary (3 Phases)

| Item | @100 | @500 | Notes |
|---|---|---|---|
| Transformer assemblies (×3) | $148.80 | $126.00 | Core + bobbin + wire + insulation + clamp |
| Resonant inductors (×3) | $33.30 | $28.00 | Kool Mu toroid + winding |
| Resonant capacitors (72 total) | $72.00 | $58.00 | 24 per phase × 3 phases |
| **Magnetics total** | **$254.10** | **$212.00** |

> [!note] Volume pricing
> At qty 500, core sets drop ~15% via direct Ferroxcube/TDK order. Litz wire pricing improves ~10% on spool quantities (≥100 m). C0G MLCCs are stable at ~$0.80/pc in volume.

## 4. EMI Filter BOM

All components from [[05-EMI Filter Design]] §9.

| Component | Part / Specification | Qty | Unit @100 | Extended @100 | Notes |
|---|---|-----|---|---|---|
| CM Choke 1 | VITROPERM W914, 3.3 mH, 60 A, 3-phase nanocrystalline | 1 | $60.00 | $60.00 | Dominant filter cost |
| CM Choke 2 | MnZn ferrite R42 stacked toroids, 1.0 mH, 60 A | 1 | $15.00 | $15.00 | TDK PC95 or 3E6 |
| X-capacitor (Cx1) | 2.2 µF, 310 VAC, X2 film (EPCOS B32924) | 3 | $2.50 | $7.50 | L-L delta |
| X-capacitor (Cx2) | 1.0 µF, 310 VAC, X2 film | 3 | $2.00 | $6.00 | L-L delta |
| Y-capacitor (Cy) | 10 nF, 250 VAC, Y2 ceramic disc | 6 | $0.50 | $3.00 | L-PE distributed |
| MOV (L-PE) | 680 VAC, EPCOS B72220S0681K101 | 3 | $3.00 | $9.00 | Surge, star to PE |
| MOV (L-L) | 680 VAC, 20 kA surge | 3 | $3.00 | $9.00 | Surge, delta |
| NTC thermistor | 10 Ω cold, 60 A rated | 3 | $2.00 | $6.00 | Inrush limiting; see [[08-Power-On Sequence and Inrush Management]] §3 for sizing |
| Bypass relay | 60 A, 600 VAC, normally open | 1 | $15.00 | $15.00 | Engages after soft-start; see [[08-Power-On Sequence and Inrush Management]] §3 for specs |
| Discharge resistors | 1 MΩ, 1 W, across each X-cap | 6 | $0.10 | $0.60 | IEC 60384-14 |
| **EMI filter total** | | | | **$131.10** | |

**EMI filter: $131.10 @100, $107.00 @500**

> [!tip] The VITROPERM nanocrystalline core at $60 is the single most expensive passive component. See §11 for Chinese alternates at $20–30.

## 5. DC Bus Capacitors

Split bus (700–920 VDC) requires high-voltage, high-ripple-current capacitors. From [[04-Thermal Budget]] §4.3 and [[01-Topology Selection]] §3.4.

| Component | Part / Specification | Qty | Unit @100 | Extended @100 | Notes |
|---|---|-----|---|---|---|
| Electrolytic (main bus) | Nichicon UBY 450 V 470 µF 125°C | 4 | $12.00 | $48.00 | 2 per rail (series for 900 V) |
| Film (bus snubber) | EPCOS B32778 500 V 20 µF polypropylene | 2 | $15.00 | $30.00 | Ripple current handling |
| Bus midpoint balance | 2× 100 µF 450 V electrolytic 125°C | 2 | $6.00 | $12.00 | Neutral point balance |
| **DC bus total** | | | | **$90.00** | |

**DC bus capacitors: $90.00 @100, $72.00 @500** — see [[08-Power-On Sequence and Inrush Management]] §1.2 for capacitance analysis and stored energy calculations.

> [!warning] 125°C capacitor rating is mandatory
> Per [[04-Thermal Budget]] §4.3: PFC heatsink reaches 95°C at worst case. Standard 105°C electrolytics at 90°C give only 28,000 hours — far below the 120,000-hour MTBF target. 125°C-rated parts provide >113,000 hours.

## 6. Thermal and Mechanical BOM

From [[04-Thermal Budget]] §3.

### 6.1 Heatsinks

| Component | Specification | Qty | Unit @100 | Extended @100 | Notes |
|---|---|-----|---|---|---|
| PFC heatsink | Al 6063-T5 extrusion, 150 × 280 × 40 mm, 25 fins | 1 | $50.00 | $50.00 | 399 W load, Rth_sa = 0.10 °C/W |
| LLC heatsink | Al 6063-T5 extrusion, 280 × 280 × 40 mm, 45 fins | 1 | $75.00 | $75.00 | 497 W load, Rth_sa = 0.06 °C/W |

### 6.2 Thermal Interface Materials

| Component | Specification | Qty | Unit @100 | Extended @100 | Notes |
|---|---|-----|---|---|---|
| Thermal pads | Bergquist GP3000S, 0.25 mm, pre-cut | ~30 pcs | $0.80 | $24.00 | All power devices + drivers |
| Thermal grease | For heatsink-to-chassis (optional) | 1 tube | $2.00 | $2.00 | Amortized |

### 6.3 Fans and Sensors

| Component | Specification | Qty | Unit @100 | Extended @100 | Notes |
|---|---|-----|---|---|---|
| Axial fan | 92 × 92 × 25 mm, PWM, 24 V, ball bearing | 3 | $35.00 | $105.00 | ~65 CFM free air, <55 dB |
| NTC temperature sensor | 10 kΩ NTC + signal conditioning | 4 | $2.00 | $8.00 | PFC, LLC, magnetics, ambient |

### 6.4 Thermal Summary

| Category | @100 | @500 |
|---|---|---|
| Heatsinks | $125.00 | $100.00 |
| Thermal pads + grease | $26.00 | $22.00 |
| Fans | $105.00 | $87.00 |
| NTC sensors | $8.00 | $6.00 |
| **Thermal total** | **$264.00** | **$215.00** |

## 7. PCB and Assembly

| Item | Specification | @100 | @500 | Notes |
|---|---|---|---|---|
| Main power PCB (AC-DC + DC-DC) | 6-layer, 2 oz/4 oz mixed copper, ~300 × 450 mm, FR4 TG170 | $120.00 | $85.00 | Heavy copper for power loops |
| Power Entry PCB (PE-CONT-01) | 2-layer, 4 oz copper, 150 × 120 mm, FR4 TG170 | $18.00 | $14.00 | NTC, relay, contactor mounting; see [[07-PCB-Layout/Power-Entry/__init\|Power Entry Board]] |
| S4 signal harness | 8-pin Micro-Fit 3.0, ~150 mm, Controller → Power Entry | $3.00 | $2.50 | Relay/contactor coil drive + feedback |
| SMD assembly | Reflow + selective wave for through-hole | $45.00 | $35.00 | ~400 placements |
| Stencil (amortized) | Laser-cut stainless steel | $5.00 | $2.00 | NRE ~$500 amortized |
| Conformal coating | Selective spray, acrylic | $8.00 | $6.00 | IP20 environment |
| **PCB + assembly total** | | **$199.00** | **$144.50** | |

> [!note] Power Entry Board Cost Impact
> The Power Entry PCB ($18) and S4 harness ($3) add ~$21 per module at qty 100. NTC, relay, and contactor component costs are unchanged — they are simply relocated from the AC-DC board to the Power Entry board. The net benefit is improved serviceability and thermal isolation at minimal cost.

## 8. Enclosure and Mechanical

From [[__init]] physical specifications: 455 × 300 × 94 mm.

| Component | Specification | Qty | Unit @100 | Extended @100 | Notes |
|---|---|-----|---|---|---|
| Sheet metal enclosure | 1.5 mm steel, 455 × 300 × 94 mm, powder coat | 1 | $65.00 | $65.00 | Intake + exhaust mesh |
| AC input connector | 3P+N+PE, 60 A panel mount | 1 | $12.00 | $12.00 | |
| DC output connector | 2-pole, 100 A panel mount | 1 | $10.00 | $10.00 | |
| CAN connector | DB9 or M12 | 1 | $3.00 | $3.00 | |
| Signal connector | Auxiliary I/O, 10-pin | 1 | $2.00 | $2.00 | |
| Bus bars | Copper, tin-plated, DC bus + output | 1 set | $20.00 | $20.00 | |
| Hardware kit | Screws, standoffs, DIN clips, labels | 1 set | $10.00 | $10.00 | |
| **Enclosure + mechanical total** | | | | **$122.00** | |

**Enclosure + mechanical: $122.00 @100, $98.00 @500**

## 9. Auxiliary Power Supply and Sensors

| Component | Specification | Qty | Unit @100 | Extended @100 | Notes |
|---|---|-----|---|---|---|
| Aux SMPS module | 12 V / 24 V, 30 W, enclosed | 1 | $15.00 | $15.00 | Fans, gate drivers, MCU |
| Current sensor (AC input) | LEM LTSR 25-NP or Allegro ACS770, Hall effect | 3 | $8.00 | $24.00 | PFC phase current sensing |
| Output current sensor | LEM HTFS 200-P or shunt + isolator | 1 | $10.00 | $10.00 | CC feedback for LLC |
| Miscellaneous passives | Decoupling caps, pull-ups, LEDs, crystal, etc. | 1 lot | $8.00 | $8.00 | |
| **Auxiliary total** | | | | **$57.00** | |

**Auxiliary: $57.00 @100, $45.00 @500**

## 10. Cost Summary

### 10.1 Per-Module Cost

| Category | @100 (USD) | @500 (USD) | % of Total (@100) |
|---|---|---|---|
| Semiconductors (SiC + ICs) | $600.60 | $483.30 | 35.2% |
| Magnetics (transformers + inductors + Cr) | $254.10 | $212.00 | 14.9% |
| EMI Filter | $131.10 | $107.00 | 7.7% |
| DC Bus Capacitors | $90.00 | $72.00 | 5.3% |
| Thermal + Fans | $264.00 | $215.00 | 15.5% |
| PCB + Assembly | $199.00 | $144.50 | 11.5% |
| Enclosure + Mechanical | $122.00 | $98.00 | 7.2% |
| Auxiliary + Sensors | $57.00 | $45.00 | 3.3% |
| Miscellaneous / margin (5%) | $8.00 | $6.00 | 0.5% |
| **Per-Module Total** | **$1,725.80** | **$1,382.80** | **100%** |

### 10.2 System-Level Cost (5-Module 150 kW Stack)

| Configuration | @100 | @500 |
|---|---|---|
| 5 × 30 kW modules | $8,629 | $6,914 |
| System CAN bus + wiring harness | ~$150 | ~$120 |
| System enclosure / rack | ~$500 | ~$400 |
| **150 kW system total** | **~$9,279** | **~$7,434** |

### 10.3 Cost Breakdown (Visual)

```
Semiconductors  ████████████████████████████████████  35%
Thermal + Fans  ████████████████                      16%
Magnetics       ███████████████                       15%
PCB + Assembly  ████████████                          12%
EMI Filter      ████████                               8%
Enclosure       ███████                                7%
DC Bus Caps     █████                                  5%
Auxiliary       ███                                    3%
Margin          █                                      1%
```

## 11. Cost Drivers and Optimization Opportunities

### 11.1 Top Cost Drivers

| Rank | Item | Extended @100 | % of BOM | Lever |
|---|---|---|---|---|
| 1 | SCTW100N120G2AG (LLC MOSFETs, 6×) | $240.00 | 14.1% | Chinese SiC alternates |
| 2 | SCTWA90N65G2V-4 (PFC MOSFETs, 6×) | $144.00 | 8.4% | Chinese SiC alternates |
| 3 | STPSC40H12C (PFC diodes, 12×) | $132.00 | 7.7% | Volume negotiation |
| 4 | PCB + assembly | $178.00 | 10.4% | Panel optimization |
| 5 | Fans (3 × 92 mm) | $105.00 | 6.2% | Chinese OEM fans |
| 6 | Heatsinks (PFC + LLC) | $125.00 | 7.3% | Custom extrusion tooling |
| 7 | C0G MLCC resonant caps (72 pcs) | $72.00 | 4.2% | Film cap alternative |
| 8 | VITROPERM nanocrystalline core | $60.00 | 3.5% | Chinese nanocrystalline |

### 11.2 Optimization Scenarios

| Optimization | Savings @100 | Savings @500 | Risk / Trade-off |
|---|---|---|---|
| Chinese SiC (BASiC Semi, SICC) for LLC MOSFETs | -$50 to -$70 | -$40 to -$55 | Qualification risk; no AEC-Q101 |
| Chinese SiC for PFC MOSFETs | -$30 to -$45 | -$25 to -$35 | Same qualification concern |
| Magnetec M-403-A vs. VITROPERM W914 | -$25 to -$35 | -$20 to -$28 | Equivalent performance, better availability |
| Film caps (WIMA FKP2) vs. C0G MLCC for Cr | -$30 to -$40 | -$25 to -$32 | Larger footprint, but higher ripple current capability |
| Chinese OEM fans (EBM-Papst equivalent) | -$25 to -$35 | -$20 to -$28 | Verify MTBF; qualification testing needed |
| Custom heatsink extrusion (NRE $2,500) | -$15/unit | -$30/unit | NRE amortizes to $25 @100, $5 @500 |
| **Total potential savings** | **-$175 to -$260** | **-$160 to -$208** | |
| **Optimized BOM** | **~$1,450–$1,530** | **~$1,160–$1,210** | |

### 11.3 Heatsink Tooling NRE

Custom extrusion die NRE is ~$2,500 one-time. Amortized per-unit cost:

| Qty | NRE per Unit | Extrusion Unit Cost | Total per Unit |
|-----|---|---|---|
| 100 | $25.00 | $85.00 | $110.00 |
| 500 | $5.00 | $70.00 | $75.00 |
| 1000 | $2.50 | $65.00 | $67.50 |

At qty 100, custom tooling saves ~$15/unit vs. off-the-shelf extrusions. Breakeven at ~50 units.

## 12. Risk Items and Alternates

| Component | Risk | Alternate | Cost Impact | Status |
|---|---|---|---|---|
| SCTW100N120G2AG | Lead time (12–16 wk), AEC-Q cost premium | C3M0030120K (Wolfspeed) | -15% per device | Validated in Wolfspeed CRD30DD12N-K |
| VITROPERM W914 | Single-source (Vacuumschmelze), opaque pricing | Magnetec M-403-A | -40% (-$25) | Equivalent µr, available ex-stock |
| TDK CGA9N4C0G2J103J (2220 C0G 630 V) | Specialty MLCC, allocation risk | WIMA FKP2 2.2 nF 630 V film | -50% (-$36) | Larger footprint; verify PCB space |
| Litz wire 44 AWG × 800 strands | Long lead specialty wire (8–12 wk) | 46 AWG × 1200 strands | Neutral | Equivalent cross-section, easier sourcing |
| Nichicon UBY 450 V 125°C | Supply chain (125°C grade is niche) | Nippon Chemi-con KMZ 450 V 125°C | Neutral | Pin-compatible, same life model |
| STPSC20H065CW (LLC diode) | Thermal bottleneck per [[04-Thermal Budget]] §4.2 | STPSC30H065CW (30 A, lower Vf) | +$3/pc (+$27 total) | Reduces Tj by ~15°C, worth the premium |

## 13. Procurement Notes

### 13.1 Long-Lead Items (Order First)

| Item | Typical Lead Time | Action |
|---|---|---|
| SiC MOSFETs (SCTW100N120G2AG) | 12–16 weeks | Order immediately at prototype stage |
| Nanocrystalline CM choke core | 8–12 weeks | Request samples from Vacuumschmelze + Magnetec |
| Litz wire (800-strand, 44 AWG) | 8–12 weeks | Source from New England Wire or Rubadue |
| Custom heatsink extrusions | 6–8 weeks (with tooling) | Tooling NRE: ~$2,500 |
| E65/32/27 core sets (3C97) | 6–8 weeks | Ferroxcube or TDK equivalent (N97) |

### 13.2 Readily Available Items

- STM32G474RE, SN65HVD230, STGAP2SiC: stock at major distributors
- X/Y capacitors, MOVs, NTC thermistors: commodity parts, 2–4 week lead
- Sheet metal enclosure: 3–4 weeks from China fabricator
- Fans, connectors, hardware: stock items

## 14. Cross-Reference Verification

### 14.1 Semiconductor Quantity Check

| Device | Topology Requirement | BOM Qty | Match |
|---|---|---|---|
| PFC MOSFETs (650 V) | Vienna: 2 per phase × 3 phases | 6 | Yes |
| PFC Schottky diodes (1200 V) | Vienna: 4 per phase × 3 phases | 12 | Yes |
| LLC primary MOSFETs (1200 V) | Half-bridge: 2 per phase × 3 phases | 6 | Yes |
| LLC secondary diodes (650 V) | Rectifier: 3 per phase × 3 phases | 9 | Yes |
| Gate drivers | PFC (3 half-bridges) + LLC (3 half-bridges) | 6 | Yes |
| MCU | Single-controller architecture | 1 | Yes |
| CAN transceiver | Inter-module stacking bus | 1 | Yes |

### 14.2 Volume Discount Consistency

| Category | @100 | @500 | Discount | Expected Range |
|---|---|---|---|---|
| Semiconductors | $600.60 | $483.30 | 19.5% | 15–25% — Yes |
| Magnetics | $254.10 | $212.00 | 16.6% | 15–20% — Yes |
| EMI Filter | $131.10 | $107.00 | 18.4% | 15–25% — Yes |
| DC Bus Caps | $90.00 | $72.00 | 20.0% | 15–25% — Yes |
| Thermal | $264.00 | $215.00 | 18.6% | 15–25% — Yes |
| PCB + Assembly | $199.00 | $144.50 | 27.4% | 25–35% — Yes |
| Enclosure | $122.00 | $98.00 | 19.7% | 15–25% — Yes |
| Auxiliary | $57.00 | $45.00 | 21.1% | 15–25% — Yes |

All volume discounts fall within the expected 15–35% range for qty 100 → qty 500 scaling.

## 15. References

- [[01-Topology Selection]] — Architecture, semiconductor selection, design decisions
- [[02-Magnetics Design]] — Transformer, inductor, resonant capacitor specifications
- [[03-LLC Gain Curve Verification]] — LLC operating points validation
- [[04-Thermal Budget]] — Loss breakdown, heatsink sizing, component thermal data
- [[05-EMI Filter Design]] — EMI filter component selection and sizing
- [[06-Firmware Architecture]] — MCU, CAN transceiver, current sensors
- Mouser / Digi-Key — Distributor pricing reference (2025-2026)
- Ferroxcube E65/32/27 datasheet — Core pricing via authorized distributors
- Magnetics Inc. Kool Mu catalog — Powder core pricing
- Vacuumschmelze VITROPERM 500F — Nanocrystalline core pricing

---

## Revision History

| Rev | Date | Author | Changes |
|-----|---|---|---|
| 0.1 | 2026-02-22 | Manas Pradhan | Initial draft |

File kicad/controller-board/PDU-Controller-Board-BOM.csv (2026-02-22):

value | footprint | quantity | references
4.7uF | <pcbnew.LIB_ID; proxy of <Swig Object of type 'LIB_ID *' at 0x177000510> > | 2 | ['C35', 'C9']
20pF | <pcbnew.LIB_ID; proxy of <Swig Object of type 'LIB_ID *' at 0x177000540> > | 2 | ['CY4', 'CY2']
20pF | <pcbnew.LIB_ID; proxy of <Swig Object of type 'LIB_ID *' at 0x177000570> > | 2 | ['CY3', 'CY1']
100uF | <pcbnew.LIB_ID; proxy of <Swig Object of type 'LIB_ID *' at 0x177000510> > | 1 | ['C34']
4.7uF | <pcbnew.LIB_ID; proxy of <Swig Object of type 'LIB_ID *' at 0x177000540> > | 1 | ['C33']
100uF | <pcbnew.LIB_ID; proxy of <Swig Object of type 'LIB_ID *' at 0x177000570> > | 1 | ['C32']
100nF | <pcbnew.LIB_ID; proxy of <Swig Object of type 'LIB_ID *' at 0x177000510> > | 5 | ['C31', 'C13', 'C10', 'C6', 'C3']
100nF | <pcbnew.LIB_ID; proxy of <Swig Object of type 'LIB_ID *' at 0x177000540> > | 5 | ['C30', 'C27', 'C12', 'C5', 'C2']
100nF | <pcbnew.LIB_ID; proxy of <Swig Object of type 'LIB_ID *' at 0x177000570> > | 5 | ['C29', 'C11', 'C7', 'C4', 'C1']
1uF | <pcbnew.LIB_ID; proxy of <Swig Object of type 'LIB_ID *' at 0x177000510> > | 1 | ['C28']
10nF | <pcbnew.LIB_ID; proxy of <Swig Object of type 'LIB_ID *' at 0x177000570> > | 2 | ['C26', 'C23']
10nF | <pcbnew.LIB_ID; proxy of <Swig Object of type 'LIB_ID *' at 0x177000510> > | 2 | ['C25', 'C22']
10nF | <pcbnew.LIB_ID; proxy of <Swig Object of type 'LIB_ID *' at 0x177000540> > | 2 | ['C24', 'C21']
100pF | <pcbnew.LIB_ID; proxy of <Swig Object of type 'LIB_ID *' at 0x177000570> > | 2 | ['C20', 'C17']
100pF | <pcbnew.LIB_ID; proxy of <Swig Object of type 'LIB_ID *' at 0x177000510> > | 2 | ['C19', 'C16']
100pF | <pcbnew.LIB_ID; proxy of <Swig Object of type 'LIB_ID *' at 0x177000540> > | 2 | ['C18', 'C15']
10uF | <pcbnew.LIB_ID; proxy of <Swig Object of type 'LIB_ID *' at 0x177000570> > | 1 | ['C14']
1uF | <pcbnew.LIB_ID; proxy of <Swig Object of type 'LIB_ID *' at 0x177000540> > | 1 | ['C8']
PLC_Coupler | <pcbnew.LIB_ID; proxy of <Swig Object of type 'LIB_ID *' at 0x177000510> > | 1 | ['T1']
PESD2CAN | <pcbnew.LIB_ID; proxy of <Swig Object of type 'LIB_ID *' at 0x177000540> > | 1 | ['D1']
2A_PTC | <pcbnew.LIB_ID; proxy of <Swig Object of type 'LIB_ID *' at 0x177000570> > | 1 | ['F1']
220R | <pcbnew.LIB_ID; proxy of <Swig Object of type 'LIB_ID *' at 0x177000510> > | 1 | ['FB3']
330R | <pcbnew.LIB_ID; proxy of <Swig Object of type 'LIB_ID *' at 0x177000540> > | 1 | ['FB2']
220R | <pcbnew.LIB_ID; proxy of <Swig Object of type 'LIB_ID *' at 0x177000570> > | 1 | ['FB1']
10k | <pcbnew.LIB_ID; proxy of <Swig Object of type 'LIB_ID *' at 0x177000510> > | 3 | ['R26', 'R17', 'R14']
10k | <pcbnew.LIB_ID; proxy of <Swig Object of type 'LIB_ID *' at 0x177000540> > | 3 | ['R25', 'R16', 'R13']
1k | <pcbnew.LIB_ID; proxy of <Swig Object of type 'LIB_ID *' at 0x177000570> > | 2 | ['R24', 'R21']
1k | <pcbnew.LIB_ID; proxy of <Swig Object of type 'LIB_ID *' at 0x177000510> > | 2 | ['R23', 'R20']
1k | <pcbnew.LIB_ID; proxy of <Swig Object of type 'LIB_ID *' at 0x177000540> > | 2 | ['R22', 'R19']
10k | <pcbnew.LIB_ID; proxy of <Swig Object of type 'LIB_ID *' at 0x177000570> > | 2 | ['R18', 'R15']
120 | <pcbnew.LIB_ID; proxy of <Swig Object of type 'LIB_ID *' at 0x177000570> > | 1 | ['R_TERM']
33 | <pcbnew.LIB_ID; proxy of <Swig Object of type 'LIB_ID *' at 0x177000510> > | 4 | ['R12', 'R9', 'R6', 'R3']
33 | <pcbnew.LIB_ID; proxy of <Swig Object of type 'LIB_ID *' at 0x177000540> > | 4 | ['R11', 'R8', 'R5', 'R2']
33 | <pcbnew.LIB_ID; proxy of <Swig Object of type 'LIB_ID *' at 0x177000570> > | 4 | ['R10', 'R7', 'R4', 'R1']
Fan_Conn | <pcbnew.LIB_ID; proxy of <Swig Object of type 'LIB_ID *' at 0x177000510> > | 1 | ['J1']
SMA_PLC | <pcbnew.LIB_ID; proxy of <Swig Object of type 'LIB_ID *' at 0x177000540> > | 1 | ['P7']
RJ45_ETH | <pcbnew.LIB_ID; proxy of <Swig Object of type 'LIB_ID *' at 0x177000570> > | 1 | ['P6']
Power_Conn | <pcbnew.LIB_ID; proxy of <Swig Object of type 'LIB_ID *' at 0x177000510> > | 1 | ['P5']
CAN_Conn | <pcbnew.LIB_ID; proxy of <Swig Object of type 'LIB_ID *' at 0x177000540> > | 1 | ['P4']
Analog_Sense | <pcbnew.LIB_ID; proxy of <Swig Object of type 'LIB_ID *' at 0x177000570> > | 1 | ['P3']
LLC_PWM | <pcbnew.LIB_ID; proxy of <Swig Object of type 'LIB_ID *' at 0x177000510> > | 1 | ['P2']
PFC_PWM | <pcbnew.LIB_ID; proxy of <Swig Object of type 'LIB_ID *' at 0x177000540> > | 1 | ['P1']
25MHz | <pcbnew.LIB_ID; proxy of <Swig Object of type 'LIB_ID *' at 0x177000570> > | 1 | ['Y2']
8MHz | <pcbnew.LIB_ID; proxy of <Swig Object of type 'LIB_ID *' at 0x177000510> > | 1 | ['Y1']
24LC128 | <pcbnew.LIB_ID; proxy of <Swig Object of type 'LIB_ID *' at 0x177000540> > | 1 | ['U9']
TPS7A20_3V3A | <pcbnew.LIB_ID; proxy of <Swig Object of type 'LIB_ID *' at 0x177000570> > | 1 | ['U8']
OPA2376 | <pcbnew.LIB_ID; proxy of <Swig Object of type 'LIB_ID *' at 0x177000510> > | 1 | ['U7']
OPA2376 | <pcbnew.LIB_ID; proxy of <Swig Object of type 'LIB_ID *' at 0x177000540> > | 1 | ['U6']
OPA2376 | <pcbnew.LIB_ID; proxy of <Swig Object of type 'LIB_ID *' at 0x177000570> > | 1 | ['U5']
QCA7000 | <pcbnew.LIB_ID; proxy of <Swig Object of type 'LIB_ID *' at 0x177000510> > | 1 | ['U4']
W5500 | <pcbnew.LIB_ID; proxy of <Swig Object of type 'LIB_ID *' at 0x177000540> > | 1 | ['U3']
TCAN330 | <pcbnew.LIB_ID; proxy of <Swig Object of type 'LIB_ID *' at 0x177000570> > | 1 | ['U2']
STM32G474RETx | <pcbnew.LIB_ID; proxy of <Swig Object of type 'LIB_ID *' at 0x177000510> > | 1 | ['U1']
MountingHole_3.2mm | <pcbnew.LIB_ID; proxy of <Swig Object of type 'LIB_ID *' at 0x177000540> > | 2 | ['MH', 'MH']
MountingHole_3.2mm | <pcbnew.LIB_ID; proxy of <Swig Object of type 'LIB_ID *' at 0x177000570> > | 1 | ['MH']
MountingHole_3.2mm | <pcbnew.LIB_ID; proxy of <Swig Object of type 'LIB_ID *' at 0x177000510> > | 1 | ['MH']

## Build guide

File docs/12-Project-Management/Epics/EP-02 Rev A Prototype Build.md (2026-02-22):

---
tags: [PDU, project-management, epic, phase-1, prototype, assembly]
created: 2026-02-22
---

# EP-02 — Rev A Prototype Build

> **Phase 1 | Duration: 8 weeks | Lead: PE**
> Gate exit: 5 units assembled and inspected. MCU boots on a custom board. All power rails verified. Gate driver waveforms captured—no assembly defects blocking bring-up.

---

## Epic Summary

This epic covers receiving bare PCBs and components, assembling 5 Rev A prototype units across 5 boards each, performing board-level verification (smoke test, rail checks, MCU boot), and preparing units for firmware bring-up. Power devices and custom magnetics are hand-soldered; SMT passives are placed by PCBA service.

**Entry criteria:** Gerbers sent, component POs placed (EP-01 complete).
**Exit criteria:** 5 units pass board-level test checklist; MCU runs blinky on target board.

---

## Stories

### Board Assembly

#### EP-02-001: Receive and Inspect Bare PCBs
| Field | Value |
|---|---|
| **Assignee** | PCB |
| **Size** | S (2 days) |
| **Status** | Backlog |
| **Depends on** | EP-01-012 |
| **Blocks** | EP-02-002 |

**Description:** Receive bare boards from fabricator. Perform incoming inspection: verify layer count, copper weight, surface finish (ENIG), board thickness, drill accuracy, impedance coupon test results (if ordered).

**Acceptance criteria:**
- [ ] All 5 board types received (6 sets each)
- [ ] Visual inspection: no delamination, scratches, or solder mask defects
- [ ] Impedance test coupon within ±10% of target (Controller board: 50 ohm single-ended)
- [ ] Stack-up cross-section matches specification (if ordered)

---

#### EP-02-002: SMT Assembly — Passive Components and ICs
| Field | Value |
|---|---|
| **Assignee** | PROC (coordinate PCBA vendor), PCB |
| **Size** | M (8 days including vendor turnaround) |
| **Status** | Backlog |
| **Depends on** | EP-02-001, EP-01-008 |
| **Blocks** | EP-02-003 |

**Description:** Send bare boards + component kits to PCBA service for SMT placement of passives (resistors, capacitors, inductors) and ICs (STM32G474RE, gate driver support ICs, CAN transceiver, LDOs, op-amps). Exclude power semiconductors (hand-solder) and through-hole magnetics.

**Acceptance criteria:**
- [ ] PCBA vendor confirms component placement matches centroid file
- [ ] X-ray inspection of QFP/QFN packages (MCU, gate drivers) — no bridging or voids
- [ ] AOI (Automated Optical Inspection) report clean
- [ ] 6 sets of each board returned

---

#### EP-02-003: Hand-Solder Power Semiconductors and Magnetics
| Field | Value |
|---|---|
| **Assignee** | PE |
| **Size** | L (15 days — 3 days per unit × 5 units) |
| **Status** | Backlog |
| **Depends on** | EP-02-002, EP-01-004, EP-01-005 |
| **Blocks** | EP-02-006 |

**Description:** Hand-solder SiC MOSFETs (D2PAK-7L package), SiC Schottky diodes, gate driver ICs (STGAP2SiC), EMI filter chokes, LLC transformer, resonant inductors, and bus bar connections. Apply thermal interface material under power devices.

**Per unit (5 boards):**
| Board | Hand-solder items |
|---|---|
| AC-DC | 6× SiC MOSFETs, 12× SiC diodes, EMI chokes, boost inductors |
| DC-DC | 6× SiC MOSFETs, 12× SiC diodes, 3× LLC transformers, 3× resonant inductors |
| Power Entry | NTC thermistors, bypass relay, output contactor |
| Aux PSU | Flyback transformer, optocouplers |
| Controller | CAN transceiver (if through-hole), test headers |

**Acceptance criteria:**
- [ ] Solder joints inspected under microscope (no cold joints, bridging, or lifted pads)
- [ ] TIM applied to all power device thermal pads (verified by slight squeeze-out)
- [ ] Magnetics mounted with correct polarity (dot convention verified)
- [ ] 5 complete units assembled

---

### Mechanical Assembly

#### EP-02-004: Assemble Bus Bars and Inter-Board Connections
| Field | Value |
|---|---|
| **Assignee** | ME |
| **Size** | M (5 days) |
| **Status** | Backlog |
| **Depends on** | EP-02-003 |
| **Blocks** | EP-02-006 |

**Description:** Install laminated bus bars (P2 DC bus, 920 V rated, 40 A) and output bus bars (100 A, M8 studs). Connect inter-board signal harnesses (gate drive, ADC sense, CAN, control). Torque all power connections per [[10-Mechanical Integration]] specifications.

**Acceptance criteria:**
- [ ] Bus bar torque values documented (M6: 4.5 Nm, M8: 10 Nm)
- [ ] Inter-board connector pinout verified against schematic
- [ ] Hi-pot pre-test between bus bar and chassis (1000 VDC, 1 s) — no breakdown
- [ ] 5 units wired

---

#### EP-02-005: Mount Boards to Heatsink and Enclosure
| Field | Value |
|---|---|
| **Assignee** | ME |
| **Size** | M (5 days) |
| **Status** | Backlog |
| **Depends on** | EP-02-004, EP-01-006 |
| **Blocks** | EP-02-006 |

**Description:** Mount AC-DC and DC-DC boards to heatsink using thermal pads and mounting screws. Install Controller and Aux PSU boards on standoffs. Mount fans. Route airflow ducting. Install AC input and DC output connectors on enclosure panel.

**Acceptance criteria:**
- [ ] All boards mechanically secured (screw torque: 0.5 Nm for PCB, 1.0 Nm for heatsink)
- [ ] TIM compression verified (0.25 mm target, measured at 3 points per board)
- [ ] Fans spin freely, airflow direction correct (intake → heatsink → exhaust)
- [ ] Connector panel accessible (AC input terminal, DC output studs, CAN connector)

---

### Board-Level Verification

#### EP-02-006: Board-Level Smoke Test — All 5 Boards
| Field | Value |
|---|---|
| **Assignee** | PE |
| **Size** | S (3 days) |
| **Status** | Backlog |
| **Depends on** | EP-02-005, EP-01-013, EP-01-014 |
| **Blocks** | EP-02-007, EP-02-008 |

**Description:** First power-on with current-limited bench supply. Verify all power rails (3.3 V, 5 V, 12 V, 18 V gate drive, −5 V gate drive) within tolerance. Check quiescent current draw. Inspect for thermal anomalies with thermal camera.

**Per board checklist:**
| Board | Tests |
|---|---|
| Aux PSU | 12 V input → all isolated outputs; measure ripple |
| Controller | 3.3 V rail, MCU current draw, LED blink, JTAG connect |
| Power Entry | NTC resistance, relay coil drive, contactor coil drive |
| AC-DC | Gate driver supply rails (18 V / −5 V), bootstrap cap charge |
| DC-DC | Gate driver supply rails, LLC half-bridge midpoint (no ringing) |

**Acceptance criteria:**
- [ ] All rails within ±5% of nominal
- [ ] No components exceed 50 degC above ambient at idle
- [ ] Total quiescent current < 8 W (per project spec)
- [ ] No magic smoke released on any of 5 units

---

#### EP-02-007: MCU Boot and JTAG Verification
| Field | Value |
|---|---|
| **Assignee** | FW |
| **Size** | S (2 days) |
| **Status** | Backlog |
| **Depends on** | EP-02-006 |
| **Blocks** | EP-03-001 |

**Description:** Connect JTAG/SWD probe to Controller board. Verify MCU device ID (STM32G474RE). Flash basic firmware (LED blink, UART printf). Verify clock configuration (170 MHz from HSE). Test GPIO toggling speed.

**Acceptance criteria:**
- [ ] SWD connection established on all 5 units
- [ ] Device ID matches STM32G474RET6 (0x469)
- [ ] LED blink at 1 Hz confirmed
- [ ] UART debug output at 115200 baud confirmed
- [ ] HSE crystal oscillator running (verify with scope on MCO pin)

---

#### EP-02-008: Gate Driver Waveform Capture
| Field | Value |
|---|---|
| **Assignee** | PE |
| **Size** | M (5 days) |
| **Status** | Backlog |
| **Depends on** | EP-02-006, EP-02-007 |
| **Blocks** | EP-03-004, EP-03-006 |

**Description:** With HRTIM generating test PWM (50% duty, 65 kHz for PFC, 150 kHz for LLC), capture gate driver output waveforms on all 12 channels (6 PFC + 6 LLC). Verify rise time, fall time, dead-time, and ringing.

**Measurement targets:**
| Parameter | PFC (65 kHz) | LLC (150 kHz) | Tool |
|---|---|---|---|
| Rise time (10–90%) | < 30 ns | < 20 ns | 500 MHz scope + diff probe |
| Fall time | < 30 ns | < 20 ns | Same |
| Dead-time | 300 ± 50 ns | 100 ± 30 ns | Same |
| Gate voltage (+) | 18 ± 1 V | 18 ± 1 V | Same |
| Gate voltage (−) | −5 ± 0.5 V | −5 ± 0.5 V | Same |
| Ringing pk-pk | < 3 V | < 3 V | Same |

**Acceptance criteria:**
- [ ] All 12 channels waveform-captured and saved
- [ ] Dead-time within spec on all channels
- [ ] No DESAT false trips during test PWM
- [ ] Gate ringing < 3 V pk-pk (if not, gate resistor adjustment noted)

---

#### EP-02-009: ADC Channel Verification
| Field | Value |
|---|---|
| **Assignee** | FW, PE |
| **Size** | S (3 days) |
| **Status** | Backlog |
| **Depends on** | EP-02-007 |
| **Blocks** | EP-03-003 |

**Description:** Apply known voltages/currents to each ADC input channel and verify firmware readings. Test all 5 ADC instances, injected and regular groups. Verify HRTIM ADC trigger routing per [[06-Firmware-Design/06-ADC Pipeline and DMA Configuration]].

| Test | Method | Expected |
|---|---|---|
| V_bus sense | Apply 700 VDC via divider test point | ADC reads 700 ± 5 V |
| Phase current | Inject 10 A via current probe | ADC reads 10 ± 0.2 A |
| NTC temperature | Apply 10k resistor (simulates 25 degC) | ADC reads 25 ± 2 degC |
| V_aux_12V | Measure rail directly | ADC reads 12.0 ± 0.2 V |

**Acceptance criteria:**
- [ ] All ADC channels respond to stimulus
- [ ] Calibration offsets recorded for each unit (stored in flash)
- [ ] DMA circular buffer operating correctly (regular group)
- [ ] HRTIM trigger routing verified (injected conversions sync to PWM center)

---

#### EP-02-010: CAN Bus Communication Test
| Field | Value |
|---|---|
| **Assignee** | FW-COM |
| **Size** | S (2 days) |
| **Status** | Backlog |
| **Depends on** | EP-02-007 |
| **Blocks** | EP-03-014 |

**Description:** Connect 2 prototype units via CAN bus (120 ohm termination). Verify basic CAN communication: send/receive test frames at 500 kbps. Test FDCAN Rx FIFO, Tx mailbox, and error counters.

**Acceptance criteria:**
- [ ] Loopback test passes on each unit individually
- [ ] Two-node communication verified (ping-pong at 10 ms interval)
- [ ] Bus-off recovery tested (short bus, verify auto-recovery)
- [ ] DIP switch node ID read correctly

---

### Documentation and Issue Tracking

#### EP-02-011: Create Rev A Issue Tracker
| Field | Value |
|---|---|
| **Assignee** | PM |
| **Size** | XS (0.5 days) |
| **Status** | Backlog |
| **Depends on** | EP-02-006 |
| **Blocks** | EP-05-001 |

**Description:** Create a structured issue log for all Rev A findings: schematic errors, layout issues, assembly difficulties, thermal anomalies, and firmware bring-up blockers. Each issue gets severity (critical/major/minor), owner, and target resolution phase.

**Acceptance criteria:**
- [ ] Issue tracker template created (Markdown table or spreadsheet)
- [ ] All board-level test findings logged
- [ ] Issues categorized by board and severity

---

#### EP-02-012: Photograph and Document Assembly Process
| Field | Value |
|---|---|
| **Assignee** | ME |
| **Size** | XS (1 day) |
| **Status** | Backlog |
| **Depends on** | EP-02-005 |
| **Blocks** | EP-09-007 |

**Description:** Photograph each assembly step for future manufacturing documentation. Document torque values, TIM application, bus bar routing, and connector crimping. This becomes the basis for production assembly instructions.

**Acceptance criteria:**
- [ ] Photo set covering all assembly steps
- [ ] Notes on any assembly difficulties or recommended sequence changes

---

#### EP-02-013: Transformer First-Article Inspection
| Field | Value |
|---|---|
| **Assignee** | PE |
| **Size** | S (2 days) |
| **Status** | Backlog |
| **Depends on** | EP-01-005 |
| **Blocks** | EP-02-003 |

**Description:** Receive custom LLC transformers from vendor. Perform incoming inspection: measure magnetizing inductance (target 258 uH ± 10%), leakage inductance (target 10 uH ± 20%), DCR (both windings), turns ratio (n=2), and hipot (4 kVAC, 60 s primary-to-secondary).

**Acceptance criteria:**
- [ ] Lm within 232–284 uH
- [ ] Leakage inductance within 8–12 uH
- [ ] Hipot passed at 4 kVAC for 60 s (no breakdown, leakage < 1 mA)
- [ ] DCR within ±15% of design value
- [ ] First-article inspection report filed

---

#### EP-02-014: Resonant Tank Parameter Measurement
| Field | Value |
|---|---|
| **Assignee** | PE |
| **Size** | S (2 days) |
| **Status** | Backlog |
| **Depends on** | EP-02-013 |
| **Blocks** | EP-03-006 |

**Description:** Measure actual resonant frequency of assembled LLC tank on each unit. Use impedance analyzer or frequency sweep to determine fr = 1/(2*pi*sqrt(Lr*Cr)). Compare with design target of 150.5 kHz. Record per-unit variation.

**Acceptance criteria:**
- [ ] Resonant frequency measured on all 5 units
- [ ] fr within 140–160 kHz (±7% of design center)
- [ ] Lr, Cr values back-calculated and compared with design
- [ ] Unit-to-unit variation documented (target < 3%)

---

## References

- [[12-Project-Management/__init|Project Management]] — Phase 1 entry/exit criteria
- [[10-Mechanical Integration]] — Assembly sequence and torque specifications
- [[07-PCB-Layout/__init|07-PCB Layout]] — Board design documentation
- [[02-Magnetics Design]] — Transformer and inductor specifications

---

## Revision History

| Rev | Date | Author | Changes |
|-----|---|---|---|
| 0.1 | 2026-02-22 | Manas Pradhan | Initial draft — 14 stories |

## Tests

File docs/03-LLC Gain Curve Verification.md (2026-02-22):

---
tags: [PDU, LLC, simulation, verification, SPICE, FHA]
created: 2026-02-22
status: complete
---

# LLC Gain Curve Verification — SPICE & FHA Analysis

> [!summary] Key Findings
> 1. **FHA accuracy:** 5–8% optimistic vs SPICE at low fn (below resonance); <3% error above resonance. FHA overpredicts gain in the below-resonance boost region.
> 2. ~~**ZVS issue at 1000 V** (original Vbus_max = 850 V)~~: **Resolved** — Vbus_max raised to 920 V. At 1000 V output, M = 1.09, fs ≈ 143 kHz, ZVS maintained with ~3% margin above fr2.
> 3. **200 V point loses ZVS** but this is the extreme derated case. Acceptable per [[01-Topology Selection]] §4.4.
> 4. **300–1000 V range is clean:** All constant-power operating points maintain ZVS with updated bus range.

## 1. Simulation Setup

Two complementary approaches were used:

| Method | Tool | What it Computes |
|---|---|---|
| **FHA analytical** | Python (numpy/matplotlib) | LLC gain M(fn, Q, Ln) from the exact transfer function |
| **Time-domain** | ngspice | Transient simulation of the equivalent Lr-Cr-Lm-Rac circuit, measuring RMS voltages at steady state |

Both use the same resonant tank parameters from [[02-Magnetics Design]]:

| Parameter | Value |
|---|---|
| Lr | 43 µH |
| Cr | 26 nF |
| Lm | 258 µH |
| Ln = Lm/Lr | 6.0 |
| n (turns ratio) | 2.0 |
| fr (series resonant) | 150.5 kHz |
| fr2 (parallel resonant / ZVS limit) | 139.4 kHz |
| Z0 (characteristic impedance) | 40.67 Ω |

Source files in `sim/`:
- `llc_fha_gain.py` — FHA analytical gain curves and operating point verification
- `llc_ngspice_sweep.py` — ngspice time-domain frequency sweep with FHA comparison
- `llc_sweep.cir` — ngspice netlist template

## 2. FHA Gain Curves

![[llc_gain_curves.png]]

**Top-left:** Gain M vs normalized frequency fn for Q = 0.1 to 2.0. Key features:
- All curves pass through M ≈ 1.0 at fn = 1.0 (resonance), confirming the tank is correctly tuned
- Below resonance (fn < 1): gain increases (boost mode). Peak gain is higher at low Q (light load)
- Above resonance (fn > 1): gain decreases monotonically. Higher Q curves droop faster
- Red dashed line marks the ZVS boundary at fn = 0.926

**Top-right:** Each operating point (200–1000 V) plotted on its respective Q gain curve:
- Green dots = safe ZVS margin
- Orange/red = at or beyond ZVS boundary

**Bottom-left:** Switching frequency vs output voltage. (Note: plot was generated before the Vbus_max update to 920 V. With Vbus = 920 V at 1000 V output, fs rises to ~143 kHz — above the ZVS boundary.)

**Bottom-right:** Load Q and Rac variation across the output range. Q spans 0.13–2.1, a 16:1 range reflecting the wide output voltage specification.

## 3. Operating Point Summary

| Point | Vo (V) | Vbus (V) | M required | Q | fn | fs (kHz) | ZVS |
|---|---|---|---|-----|---|---|-----|
| Min voltage | 200 | 650 | 0.308 | 2.09 | 0.548 | 82 | **NO** |
| Low voltage | 300 | 700 | 0.429 | 1.39 | 1.780 | 268 | OK |
| Mid-low | 400 | 700 | 0.571 | 0.78 | 1.925 | 290 | OK |
| **Design center** | **600** | **750** | **0.800** | **0.35** | **1.795** | **270** | **OK** |
| Nominal | 800 | 800 | 1.000 | 0.20 | 1.000 | 151 | OK |
| Max voltage | 1000 | **920** | **1.087** | 0.13 | **~0.96** | **~143** | **OK** |

> [!success] 1000 V ZVS issue — RESOLVED
> **Original issue (Vbus = 850 V):** M = 1.176, fn = 0.75, ZVS lost (19% below boundary).
>
> **Fix applied:** Vbus_max raised from 850 V to 920 V. Now at 1000 V output:
> - M = 1000 / (2 × 920/2) = **1.087**
> - fn ≈ 0.96, fs ≈ 143 kHz — **above fr2 = 139 kHz**
> - ZVS margin: ~3% above the boundary
>
> The Vienna PFC uses 1200 V SiC diodes (STPSC40H12C) and 650 V MOSFETs in a 3-level topology. At 920 V bus, each device still only blocks ~460 V — well within the 650 V MOSFET rating. No component changes needed in the PFC stage.

## 4. SPICE vs FHA Comparison

![[llc_spice_vs_fha.png]]

**Left panel:** Gain curves at four load points (Q = 0.13, 0.20, 0.35, 1.39). SPICE dots track the FHA lines but with consistent offset.

**Right panel:** FHA error relative to SPICE at the design center (Q = 0.35):
- Above resonance (fn > 1): FHA is 3–7% higher than SPICE — acceptable for initial design
- Near resonance (fn ≈ 1): FHA is 5–7% higher
- Below resonance (fn < 0.9): FHA diverges more (8–15% error) due to:
  - Square wave harmonics ignored by FHA
  - Non-sinusoidal rectifier current waveforms
  - Resonant tank operating off-resonance where harmonics carry more energy

> [!note] FHA is a useful design tool but overpredicts gain by 5–8%
> This means the actual M_max achievable is lower than FHA predicts. For the 1000 V point (M = 1.18 required), the actual SPICE gain at fn = 0.75 may be ~10% lower than FHA claims, making the ZVS issue even more severe.

## 5. ZVS Detail — 800 V and 1000 V

![[llc_zvs_detail.png]]

The zoomed view around the ZVS boundary shows:
- **800 V (fn = 1.0):** Sits exactly at resonance. ZVS margin = +8% above fr2. Safe.
- **1000 V (fn = 0.75):** Deep into the capacitive region (below fr2). Hard switching confirmed.

## 6. Peak Gain Capability

| Q | M_max (FHA) | fn at M_max | fs at M_max |
|-----|---|---|---|
| 0.10 | 2.28 | 0.500 | 75 kHz |
| 0.20 | 1.86 | 0.500 | 75 kHz |
| 0.35 | 1.34 | 0.504 | 76 kHz |
| 0.50 | 1.11 | 0.655 | 99 kHz |
| 1.00 | 1.02 | 0.925 | 139 kHz |
| 1.50 | 1.01 | 0.968 | 146 kHz |
| 2.00 | 1.00 | 0.982 | 148 kHz |

At Q = 0.13 (1000 V/10 kW load), the required M = 1.09 (with Vbus = 920 V) is achievable at fn ≈ 0.96 — within the ZVS region.

## 7. Design Actions Taken

### 7.1 Vbus_max Raised to 920 V — APPLIED

The original simulation identified ZVS loss at 1000 V output (Vbus = 850 V → M = 1.18, fn = 0.75). Three options were evaluated:

| Option | Change | M_req at 1000V | ZVS? | Impact |
|---|---|---|---|---|
| **A: Raise Vbus_max ✓** | Vbus → 920 V at 1000 V output | 1.087 | **Yes** (fn ≈ 0.96) | PFC regulates higher; 650 V MOSFETs see 460 V — OK |
| B: Change turns ratio | n = 1.75 (Ns:Np ≈ 7:4) | 1.075 at 850V bus | Marginal | Rejected — non-integer ratio complicates winding |
| C: Accept hard switching | No change | 1.176 | No | Fallback for low AC input edge case |

**Option A was adopted.** Documents updated:
- [[01-Topology Selection]] §2 architecture, §3.3 PFC specs, §3.4 bus setpoint, §4.3 LLC input, §4.4 wide-Vout strategy
- [[02-Magnetics Design]] §1 inputs, §2.3 gain table, §3.6 operating range, §4.2 flux density, §6.1 Cr voltage, §9 risk table

**Fallback (Option C):** For the rare edge case where the PFC cannot reach 920 V (e.g., low AC input at 260 V), accept brief hard switching at 1000 V with increased dead time to reduce switching loss.

### 7.2 Magnetics Impact Verified

With Vbus_max = 920 V:
- Transformer Bpeak at worst case (920 V, 143 kHz): **72 mT** — safe, margin of ~5:1 to saturation
- Cr peak voltage increases to ~460 V + resonant swing — existing 1890 V array rating is adequate
- Np = 21 is still sufficient

### 7.3 No Changes Needed for 300–800 V

The simulation confirms clean operation across the primary charging range. The 300 V point at fs = 268 kHz is well within the 300 kHz limit.

## 8. Conclusions

| Verification Item | Result |
|---|---|
| fr = 150 kHz | **Confirmed:** fr = 150.5 kHz (Lr×Cr product correct) |
| Gain M at all operating points | **Achievable** within LLC characteristic (see §3) |
| ZVS at 300–800 V | **Confirmed** — all points above fn = 0.926 |
| ZVS at 1000 V (Vbus = 920 V) | **Confirmed** — fn ≈ 0.96, 3% margin above fr2 |
| ZVS at 200 V | Expected loss (derated point, per topology selection) |
| FHA accuracy vs SPICE | **5–8% optimistic** in below-resonance region; adequate for design |
| Total magnetics losses within 2% budget | **Confirmed** in [[02-Magnetics Design]] §7 (0.5% at design center) |

> [!success] Overall Verdict
> The resonant tank design (Lr = 43 µH, Cr = 26 nF, Lm = 258 µH) is validated for the full 300–1000 V constant-power operating range. The 1000 V ZVS issue has been resolved by extending the PFC bus voltage to 700–920 V. All affected documents ([[01-Topology Selection]], [[02-Magnetics Design]]) have been updated.

---

## Revision History

| Rev | Date | Author | Changes |
|-----|---|---|---|
| 0.1 | 2026-02-22 | Manas Pradhan | Initial draft |

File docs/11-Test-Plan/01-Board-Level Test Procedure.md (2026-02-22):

---
tags: [PDU, testing, bring-up, prototype, verification, lab-procedure]
created: 2026-02-22
status: draft
---

# Board-Level Test Procedure — 30 kW PDU

> [!summary] Purpose
> This document defines the **lab-level board test procedures** for prototype bring-up and design verification of the 30 kW PDU's five independently fabricated PCBs. It covers equipment lists, standalone board test setups, step-by-step test sequences with pass/fail criteria, and test report templates. For field-level commissioning of an assembled system, see [[12-Project-Management/__init|12-Project Management]] → [[Commissioning Procedure]].

---

## 1. Lab Equipment List

### 1.1 Power Sources

| # | Equipment | Minimum Specification | Suggested Make/Model | Qty |
|:-:|---|---|---|:---:|
| 1 | 3-phase programmable AC source | 0–530 VAC L-L, 60 A/phase, 30 kVA, 45–65 Hz, PF programmable | Chroma 61845 / Pacific Power 345-AMX | 1 |
| 2 | HV DC power supply (DC bus) | 0–1000 V, 0–10 A, 5 kW | Keysight N8957A / TDK-Lambda Z+ | 1 |
| 3 | HV DC power supply (output sim) | 0–600 V, 0–5 A, 1 kW | Keysight E36234A | 1 |
| 4 | Low-voltage bench supply | 0–30 V, 0–3 A, dual channel | Rigol DP832 / Keysight E36312A | 1 |
| 5 | 24 VDC supply (relay/contactor coils) | 24 V, 3 A | Any regulated bench supply | 1 |

### 1.2 Electronic Loads

| # | Equipment | Minimum Specification | Suggested Make/Model | Qty |
|:-:|---|---|---|:---:|
| 6 | DC electronic load (main) | 30 kW, 0–1200 V, 0–100 A, CC/CV/CP modes | Chroma 63210A-1200-400 / NH Research 4760 | 1 |
| 7 | DC electronic load (bus) | 600 V, 40 A, 10 kW, CC mode | Chroma 63206A-600-840 | 1 |
| 8 | Resistive load bank | 10–100 Ω, 500 W, wirewound | Ohmite or custom | 1 set |

### 1.3 Measurement — Oscilloscope and Probes

| # | Equipment | Minimum Specification | Suggested Make/Model | Qty |
|:-:|---|---|---|:---:|
| 9 | Digital oscilloscope | ≥500 MHz, 4 ch, 12-bit ADC, ≥2.5 GS/s, math/FFT | Keysight MSOX4054A / Tektronix MSO54 | 1 |
| 10 | HV differential probes | 1500 V, 100 MHz BW | Tektronix THDP0200 / PMK BumbleBee | 2 |
| 11 | Current probe (low) | 30 A, 120 MHz BW | Tektronix TCP0030A | 2 |
| 12 | Current probe (high) | 150 A, 20 MHz BW | PEM CWT Mini HF 06 Rogowski | 2 |
| 13 | Rogowski coil (primary) | 300 A pk, 30 MHz BW | PEM CWT Ultra-mini | 3 |

### 1.4 Measurement — Meters and Analyzers

| # | Equipment | Minimum Specification | Suggested Make/Model | Qty |
|:-:|---|---|---|:---:|
| 14 | Power analyzer | 3P4W, ≥0.05% accuracy, ≥2 MHz BW, 6 ch | Yokogawa WT3000E / Hioki PW6001 | 1 |
| 15 | 6.5-digit DMM | 1000 VDC, 10 A, true-RMS | Keysight 34465A | 2 |
| 16 | LCR meter | 100 Hz–1 MHz, 4-wire | Keysight E4980AL | 1 |
| 17 | Thermal camera | ≥160×120, ±2°C, NETD ≤50 mK | FLIR E86 / InfiRay T630 | 1 |
| 18 | Thermocouple data logger | 8-ch, Type K, 0.1°C resolution | Pico TC-08 / Omega OM-DAQ-USB-2401 | 1 |
| 19 | Type K thermocouples | −40 to +260°C, adhesive-tip | — | 8 |

### 1.5 Safety Test Equipment

| # | Equipment | Minimum Specification | Suggested Make/Model | Qty |
|:-:|---|---|---|:---:|
| 20 | Hipot tester (AC) | 0–5 kV AC, 50/60 Hz, adjustable ramp, 100 mA trip | Associated Research Hypot 3705 | 1 |
| 21 | Insulation resistance tester (Megger) | 500 V / 1000 V / 2500 V DC, ≥200 GΩ range | Fluke 1555 / Megger MIT515 | 1 |
| 22 | Earth bond tester | 25 A, ≤100 mΩ, 60 s hold | Associated Research 3705 (combo) | 1 |
| 23 | Leakage current meter | 0–10 mA AC/DC, MD network per IEC 62368-1 | — | 1 |

### 1.6 Signal and Protocol Equipment

| # | Equipment | Minimum Specification | Suggested Make/Model | Qty |
|:-:|---|---|---|:---:|
| 24 | Function generator | 1 Hz–25 MHz, 2 ch, arbitrary waveform | Keysight 33500B | 1 |
| 25 | Logic analyzer | ≥16 ch, 100 MHz sampling | Saleae Logic Pro 16 | 1 |
| 26 | CAN bus interface | PCAN-USB FD, ISO 11898-compliant | Peak PCAN-USB FD | 2 |
| 27 | ST-Link V3 debugger/programmer | SWD, supports STM32G4 | STLINK-V3SET | 1 |
| 28 | CAN bus termination load | 120 Ω | Resistor + DB-9 plug | 2 |

### 1.7 Environmental

| # | Equipment | Minimum Specification | Suggested Make/Model | Qty |
|:-:|---|---|---|:---:|
| 29 | Thermal chamber (optional) | −40 to +85°C, interior ≥0.5 m³ | ESPEC / Thermotron | 1 |
| 30 | Production-spec fans | 3 × 92 mm, PWM, matching PDU spec | — | 3 |

### 1.8 Fixtures and Safety

| # | Item | Notes | Qty |
|:-:|---|---|:---:|
| 31 | DUT mounting plate | Aluminum plate with standoff holes matching all 5 boards | 1 |
| 32 | Bus bar set (P2) | Laminated Cu, 2 mm, tin-plated, matching [[00-Board Partitioning]] §4.3 | 1 |
| 33 | Signal harness S1 | 12-pin Molex Pico-Lock, Controller → AC-DC, shielded | 1 |
| 34 | Signal harness S2 | 10-pin Molex Pico-Lock, Controller → DC-DC, shielded | 1 |
| 35 | Signal harness S3 | DB-9 or M12, CAN bus + termination | 1 |
| 36 | Signal harness S4 | 8-pin Molex Micro-Fit 3.0, Controller → Power Entry | 1 |
| 37 | Power harness P1b | 3 × 10 AWG, Power Entry → AC-DC | 1 |
| 38 | Power harness P3a | 2 × 8 AWG, DC-DC → Power Entry | 1 |
| 39 | Power harness P4 | Molex Micro-Fit 3.0, 8-pin, Aux PSU → power boards | 1 |
| 40 | Power harness P5 | Molex Micro-Fit 3.0, 4-pin, Aux PSU → Controller | 1 |
| 41 | Fuses (AC input) | 80 A, 600 VAC, fast-blow (one per phase) | 3 |
| 42 | Fuse (DC output) | 125 A, 1000 VDC, fast-blow | 1 |
| 43 | E-stop mushroom button | Wired to disconnect AC source enable + load enable | 1 |
| 44 | PPE kit | HV-rated gloves (Class 0, 1000 V), safety glasses, insulating mat | 1 set |
| 45 | Discharge probe | 10 kΩ, 50 W, insulated handles, rated 1200 V | 1 |

---

## 2. Test Setup Diagrams

### 2.1 Power Entry Board — Standalone

```
                     ┌──────────────────────────────────────┐
                     │        POWER ENTRY BOARD (DUT)       │
                     │                                      │
  24 VDC Bench  ────▶│ S4 pin 6 (+24V_COIL)                 │
  Supply (3A)        │ S4 pin 8 (GND)                       │
                     │                                      │
  Function Gen ─────▶│ S4 pin 1 (RELAY_A_DRV) ─┐            │
  (3.3V logic)       │ S4 pin 2 (RELAY_B_DRV)  ├ via jumper │
                     │ S4 pin 3 (RELAY_C_DRV)  │  or MCU    │
                     │ S4 pin 4 (CONT_DRV) ────┘            │
                     │                                      │
  Reduced AC   ─────▶│ P1a (L1, L2, L3, PE)                 │
  Source (50 VAC)    │                                      │
                     │ P1b (L1_FILT, L2_FILT, L3_FILT) ───▶ Resistive Load
                     │                                      │  (10 Ω / phase)
                     │ P3a ◀─── DC Supply 50V ────────────  │
                     │ P3b ──── to DMM (contact R meas) ──  │
                     │                                      │
  Oscilloscope ─────▶│ Probe: relay coil transients         │
  Ch1: relay coil    │ Probe: contactor aux contact         │
  Ch2: S4 pin 5 FB   │                                      │
                     └──────────────────────────────────────┘
```

> [!note] Reduced Voltage
> Test the Power Entry board at **reduced AC voltage** (50 VAC) initially. Full voltage testing occurs only during system integration.

### 2.2 Aux PSU Board — Standalone

```
                     ┌──────────────────────────────────────┐
                     │         AUX PSU BOARD (DUT)          │
                     │                                      │
  HV DC Supply  ────▶│ DC Bus Input (400–920 VDC)           │
  (600V, 1A)         │                                      │
                     │ P4 pin 1 (VDRV_AC +18V) ───▶ 36 Ω / 10W resistor
                     │ P4 pin 2 (VNEG_AC −5V)  ───▶ 25 Ω / 1W resistor
                     │ P4 pin 3 (VDRV_AC_RTN)                │
                     │ P4 pin 5 (VDRV_DC +18V) ───▶ 36 Ω / 10W resistor
                     │ P4 pin 6 (VNEG_DC −5V)  ───▶ 25 Ω / 1W resistor
                     │ P4 pin 7 (VDRV_DC_RTN)                │
                     │ P5 pin 1 (+5V)          ───▶ 5 Ω / 5W resistor
                     │ P5 pin 2 (+3.3V)        ───▶ 6.6 Ω / 2W resistor
                     │ P5 pin 4 (+12V_FAN)     ───▶ 6 Ω / 25W resistor
                     │ P5 pin 3 (GND)                        │
                     │                                       │
  DMM #1 ───────────▶│ Measure each output voltage           │
  DMM #2 ───────────▶│ Measure input current                 │
  Oscilloscope ─────▶│ Ch1: +18V ripple (AC-coupled, 20MHz BW)│
                     │ Ch2: +3.3V ripple                     │
                     │ Ch3: primary FET drain (HV diff probe)│
                     └───────────────────────────────────────┘
```

### 2.3 Controller Board — Standalone

```
                     ┌──────────────────────────────────────┐
                     │       CONTROLLER BOARD (DUT)         │
                     │                                      │
  Bench Supply  ────▶│ P5 pin 1 (+5V, 1A limit)             │
  Ch1: +5V           │ P5 pin 2 (+3.3V, 0.5A limit)         │
  Ch2: +3.3V         │ P5 pin 3 (GND)                       │
                     │ P5 pin 4 (+12V, via separate supply) │
                     │                                      │
  ST-Link V3   ─────▶│ SWD header (SWDIO, SWCLK, NRST, GND) │
                     │                                      │
  PCAN-USB #1  ─────▶│ S3 (CAN_H, CAN_L) + 120Ω term        │
  PCAN-USB #2  ─────▶│ (second CAN node for traffic gen)    │
                     │                                      │
  Oscilloscope ─────▶│ Ch1: PWM_A_H (S1 pin 1)              │
                     │ Ch2: PWM_LLC_A (S2 pin 1)            │
                     │ Ch3: CAN_H (S3 pin 1)                │
                     │ Ch4: ADC test input (P3 pin 1)       │
                     │                                      │
  Function Gen ─────▶│ P3 analog input (sine wave sim)      │
                     └──────────────────────────────────────┘
```

### 2.4 AC-DC Board — Standalone

```
                     ┌──────────────────────────────────────┐
                     │        AC-DC BOARD (DUT)             │
                     │                                      │
  3-Phase AC   ─────▶│ P1b (L1_FILT, L2_FILT, L3_FILT)      │
  Source             │  via 80A fuses (per phase)           │
  (260–530 VAC)      │                                      │
                     │ Gate Drive Supply (+18V/−5V) ◀────── Aux PSU or
                     │  P4 pins 1–4                         │  bench supply
                     │                                      │
                     │ Control Harness S1 ◀──────────────── Controller or
                     │  (12-pin: 6 PWM + 3 I_SENSE +        │  function gen
                     │   V_BUS_SENSE + FAULT_PFC + GND)     │
                     │                                      │
                     │ DC Bus Output (P2) ──────────────▶  DC Electronic
                     │  DC_BUS+ / DC_BUS−                   │  Load (bus)
                     │  (920 VDC, 40A max)                  │  600V / 40A
                     │                                      │
  Power Analyzer ───▶│ 3P4W AC input + DC output            │
  Oscilloscope ─────▶│ Ch1: V_DS switching node (HV probe)  │
                     │ Ch2: I_phase (Rogowski/current probe)│
                     │ Ch3: V_bus DC (HV diff probe)        │
                     │ Ch4: gate drive signal               │
  Thermal Camera ───▶│ MOSFET / diode / inductor surfaces   │
                     └──────────────────────────────────────┘
```

### 2.5 DC-DC Board — Standalone

```
                     ┌──────────────────────────────────────┐
                     │        DC-DC BOARD (DUT)             │
                     │                                      │
  HV DC Supply  ────▶│ P2 (DC_BUS+, DC_BUS−)                │
  (0–920 VDC)        │  via bus bar + fuse                  │
  or DC load on      │                                      │
  AC-DC output       │ Gate Drive Supply (+18V/−5V) ◀────── Aux PSU or
                     │  P4 pins 5–8                         │  bench supply
                     │                                      │
                     │ Control Harness S2 ◀──────────────── Controller or
                     │  (10-pin: 6 PWM + V_OUT_SENSE +      │  function gen
                     │   I_OUT_SENSE + FAULT_LLC + GND)     │
                     │                                      │
                     │ DC Output (P3a) ─────────────────▶  DC Electronic
                     │  DC_PRE_CONT+ / DC_PRE_CONT−         │  Load (main)
                     │  (150–1000 VDC, 100A max)            │  1200V / 100A
                     │                                      │
  Power Analyzer ───▶│ DC input + DC output                 │
  Oscilloscope ─────▶│ Ch1: V_DS primary half-bridge (HV)   │
                     │ Ch2: I_resonant (Rogowski)           │
                     │ Ch3: V_out DC (HV diff probe)        │
                     │ Ch4: V_DS secondary SR (HV)          │
  Thermal Camera ───▶│ MOSFETs / diodes / transformer       │
                     └──────────────────────────────────────┘
```

### 2.6 Full System Integration

```
 3-Phase AC Source (530 VAC, 60A)
       │
       │ 80A fuses (×3)
       ▼
 ┌──────────┐   P1b    ┌──────────┐   P2 bus   ┌──────────┐
 │  Power   │ ────────▶│  AC-DC   │ ═════════▶ │  DC-DC   │
 │  Entry   │          │  Board   │  bar       │  Board   │
 │  Board   │◀─────────│          │            │          │──▶ P3a
 │          │  P3a     └────┬─────┘            └────┬─────┘
 └──┬───┬───┘               │                       │
    │   │              ┌────┴─────┐            ┌────┴─────┐
    │   │              │ Aux PSU  │◀───────────│Controller│
    │   │              │  Board   │  P5        │  Board   │
    │   │              └──────────┘            └────┬─────┘
    │   │                                           │ S3
    │   └──── P3b ──▶ DC Electronic Load (30kW)     │
    │         (via contactor)   1200V / 100A         ▼
    │                                          PCAN-USB (PC)
    │
    └──── P1a ◀── AC Source

 Power Analyzer: 3P4W on AC input + DC wiring on output (6 channels)
 Thermocouple logger: 8 × Type K on MOSFETs, diodes, transformer, ambient
 Thermal camera: positioned for top-down view of all heatsinks
 E-stop: series with AC source enable + DC load enable
```

### 2.7 Safety / Hipot Test Connections

```
  Hipot Tester                    DUT (all boards assembled, power OFF)
  ┌──────────┐
  │          │─── HV lead ──▶  Test Point (varies per test)
  │  5 kV AC │
  │          │─── Return ───▶  Chassis PE stud
  └──────────┘

  Test 1: AC input → PE     HV on P1a (L1+L2+L3 shorted) │ Return on PE
  Test 2: DC bus → PE       HV on P2 (BUS+ & BUS− shorted)│ Return on PE
  Test 3: DC output → PE    HV on P3b (OUT+ & OUT− shorted)│ Return on PE
  Test 4: Primary → Secondary  HV on P2 │ Return on P3a (primary-to-sec isolation)

  ┌────────────────────────────────────────────────────────────┐
  │  IMPORTANT: Disconnect ALL signal harnesses (S1–S4) and    │
  │  electronic loads before hipot testing. Short each domain  │
  │  internally to avoid voltage stress across components.     │
  └────────────────────────────────────────────────────────────┘
```

---

## 3. Board-Level Test Procedures

### 3.1 Power Entry Board (PE-CONT-01)

Reference: [[07-PCB-Layout/Power-Entry/__init|Power Entry Board]], [[08-Power-On Sequence and Inrush Management]]

#### 3.1.1 Visual Inspection

| Step | Action | Instrument | Pass Criteria | Record |
|:----:|---|---|---|---|
| PE-V01 | Inspect all solder joints on NTC pads (3×) for cold joints or bridges | 10× magnifier | No solder bridges, smooth fillets on 4 oz Cu | ☐ P / ☐ F |
| PE-V02 | Inspect bypass relay solder pins (3×) for complete through-hole fill | 10× magnifier | ≥75% barrel fill per IPC-A-610 Class 2 | ☐ P / ☐ F |
| PE-V03 | Inspect output contactor (TE EV200) mounting hardware | Visual | M5 bolts torqued, no cracked PCB pads | ☐ P / ☐ F |
| PE-V04 | Verify RC snubber component values (100 Ω + 47 nF × 3 sets) | Visual + marking check | Correct values, 630 VAC rated caps | ☐ P / ☐ F |
| PE-V05 | Verify flyback diode polarity on all coil drivers (3 relay + 1 contactor) | Visual | Cathode stripe toward +24V rail | ☐ P / ☐ F |
| PE-V06 | Inspect PCB slot between AC and DC zones | 10× magnifier | Slot width ≥2 mm, no solder bridges across slot | ☐ P / ☐ F |
| PE-V07 | Verify creepage: AC zone to PE ≥10 mm, DC zone to PE ≥15 mm | Ruler / caliper | Distances per [[09-Protection and Safety]] §7.1.1 | ☐ P / ☐ F |
| PE-V08 | Verify connector keying: S4 unique vs S1/S2/S3, P1a/P1b/P3a/P3b correct | Mate check | Cannot cross-mate with wrong harness | ☐ P / ☐ F |

#### 3.1.2 Continuity and Resistance

| Step | Action | Instrument / Settings | Pass Criteria | Record |
|:----:|---|---|---|---|
| PE-R01 | Measure NTC cold resistance (3×) at ambient temperature | DMM, Ω mode | 10 Ω ±20% at 25°C (8–12 Ω) | NTC_A: ___ Ω, NTC_B: ___ Ω, NTC_C: ___ Ω |
| PE-R02 | Measure NTC-to-NTC resistance balance | DMM | Max deviation between 3 NTCs ≤15% | ☐ P / ☐ F |
| PE-R03 | Verify bypass relay contact resistance (each relay, contacts forced closed) | DMM, mΩ mode (or 4-wire) | <5 mΩ per contact | Relay_A: ___ mΩ, Relay_B: ___ mΩ, Relay_C: ___ mΩ |
| PE-R04 | Measure contactor contact resistance (manually close or energize at 24 V) | DMM, mΩ (4-wire, 1A source) | <1 mΩ (TE EV200 spec: <0.3 mΩ) | ___ mΩ |
| PE-R05 | Verify contactor auxiliary contact: open when coil de-energized, closed when energized | DMM, continuity | Open >1 MΩ, Closed <1 Ω | ☐ P / ☐ F |
| PE-R06 | Insulation resistance: AC zone to PE | Megger, 500 VDC, 60 s | >100 MΩ | ___ MΩ |
| PE-R07 | Insulation resistance: DC zone to PE | Megger, 1000 VDC, 60 s | >100 MΩ | ___ MΩ |
| PE-R08 | Insulation resistance: AC zone to DC zone | Megger, 1000 VDC, 60 s | >100 MΩ | ___ MΩ |
| PE-R09 | Continuity: PE stud to chassis mounting hole | DMM, Ω | <0.1 Ω | ___ Ω |
| PE-R10 | Continuity: each phase P1a pin to corresponding P1b pin (through NTC) | DMM | 10 ±2 Ω (NTC in path) | L1: ___ Ω, L2: ___ Ω, L3: ___ Ω |
| PE-R11 | Continuity: P3a to P3b (through contactor, coil energized) | DMM | <5 mΩ (contactor + trace) | ___ mΩ |
| PE-R12 | Verify no short: P3a+ to P3a− | DMM | >10 MΩ | ☐ P / ☐ F |

#### 3.1.3 First Power-On

| Step | Action | Instrument / Settings | Pass Criteria | Record |
|:----:|---|---|---|---|
| PE-P01 | Apply 24 VDC to S4 pin 6 / pin 8. Measure quiescent current | Bench supply, 24 V, 0.1 A limit | <10 mA (no coils energized) | ___ mA |
| PE-P02 | Drive RELAY_A_DRV high (3.3 V). Verify relay A clicks, measure coil current | Oscilloscope Ch1 on coil, DMM | Relay actuates; coil I ≈ 40–50 mA at 24 V | ___ mA |
| PE-P03 | Repeat PE-P02 for RELAY_B_DRV and RELAY_C_DRV | Same | Same criteria | B: ___ mA, C: ___ mA |
| PE-P04 | Drive CONT_DRV high (3.3 V). Verify contactor clicks, check aux contact S4 pin 5 | Oscilloscope, DMM | Contactor actuates within 20 ms; aux FB goes low | Actuation time: ___ ms |
| PE-P05 | De-energize contactor. Verify aux contact returns within 20 ms | Oscilloscope trigger on coil | Aux FB goes high within 20 ms | Release time: ___ ms |
| PE-P06 | Apply 50 VAC (reduced) 3-phase to P1a via current-limited AC source (5 A limit) | AC source, oscilloscope | No arcing, NTC current ≈ 5 A peak per phase | I_pk: ___ A |
| PE-P07 | With relays energized (NTC bypassed), measure voltage drop P1a → P1b per phase at 5 A | DMM AC mV | <100 mV per phase (relay contact drop) | L1: ___ mV, L2: ___ mV, L3: ___ mV |
| PE-P08 | Apply 50 VDC to P3a. Close contactor. Measure V at P3b | DMM | V_P3b = V_P3a ±0.1 V (contact drop negligible at low current) | ☐ P / ☐ F |
| PE-P09 | Monitor relay coil voltage transients on de-energize (check flyback diode function) | Oscilloscope, Ch1 across coil | Clamp voltage <30 V (flyback diode limits spike) | V_clamp: ___ V |

#### 3.1.4 Functional Tests

| Step | Action | Instrument / Settings | Pass Criteria | Record |
|:----:|---|---|---|---|
| PE-F01 | Full NTC inrush test: apply 260 VAC 3-phase, DC bus cap load (470 µF × 2 on each rail) connected via P1b → rectifier → caps. Measure peak inrush per phase | Rogowski coils, oscilloscope | I_peak ≤ 40 A/phase at 260 VAC (per [[08-Power-On Sequence and Inrush Management]] §2.1) | I_pk: ___ A |
| PE-F02 | Repeat PE-F01 at 530 VAC | Same | I_peak ≤ 75 A/phase | I_pk: ___ A |
| PE-F03 | Contactor contact resistance under 100 A DC load (requires system integration or external DC supply + load) | 4-wire mΩ meter | <1 mΩ (matches TE EV200 datasheet: <0.3 mΩ) | ___ mΩ |

#### 3.1.5 Protection Tests

| Step | Action | Instrument / Settings | Pass Criteria | Record |
|:----:|---|---|---|---|
| PE-X01 | Contactor welding detection: de-energize contactor coil; verify aux contact opens | DMM on S4 pin 5 | Aux contact open within 20 ms; firmware would flag WELD_FAULT if stuck | ☐ P / ☐ F |
| PE-X02 | Simulate contactor weld: hold S4 pin 5 low while coil is off; verify fault logic (requires controller firmware or manual check) | Logic analyzer on S4 | Fault flag set when aux disagrees with coil command | ☐ P / ☐ F |

#### 3.1.6 Thermal Characterization

| Step | Action | Instrument / Settings | Pass Criteria | Record |
|:----:|---|---|---|---|
| PE-T01 | 1-hour continuous run at 60 A AC (requires system integration). Monitor NTC body (bypassed), relay body, contactor body temperatures | Thermocouple logger + thermal camera | Relay body <85°C, contactor body <80°C, no hot spots | Relay: ___°C, Contactor: ___°C |
| PE-T02 | 10× rapid NTC inrush cycles (530 VAC, 30 s interval). Monitor NTC disc temperature | Thermocouple on NTC disc | NTC disc <200°C (well within 150 J energy rating) | T_max: ___°C |

---

### 3.2 Aux PSU Board (AUX-PSU-01)

Reference: [[07-PCB-Layout/Aux-PSU/__init|Aux PSU Board]]

#### 3.2.1 Visual Inspection

| Step | Action | Instrument | Pass Criteria | Record |
|:----:|---|---|---|---|
| AX-V01 | Inspect flyback transformer solder joints and isolation slot (4 mm min) | 10× magnifier | No bridges across isolation barrier, slot width ≥4 mm | ☐ P / ☐ F |
| AX-V02 | Verify Y-capacitor placement (primary to secondary, across slot) | Visual | Only Y-rated caps cross the isolation barrier | ☐ P / ☐ F |
| AX-V03 | Verify optocoupler/feedback IC orientation | Visual | Pin 1 dot matches silkscreen | ☐ P / ☐ F |
| AX-V04 | Inspect output electrolytic capacitor polarity (all rails) | Visual | Stripe (negative) matches PCB marking | ☐ P / ☐ F |
| AX-V05 | Verify creepage primary → secondary ≥14 mm, clearance ≥8 mm | Ruler/caliper | Per [[09-Protection and Safety]] §7.1.1 | ☐ P / ☐ F |

#### 3.2.2 Continuity and Resistance

| Step | Action | Instrument / Settings | Pass Criteria | Record |
|:----:|---|---|---|---|
| AX-R01 | Insulation resistance: DC bus input to all secondary outputs (shorted together) | Megger, 1000 VDC, 60 s | >100 MΩ | ___ MΩ |
| AX-R02 | Insulation resistance: Domain A (VDRV_AC) to Domain B (VDRV_DC) | Megger, 500 VDC, 60 s | >50 MΩ (functional isolation) | ___ MΩ |
| AX-R03 | Measure flyback primary winding DCR | LCR meter, 1 kHz | Per design (typically 2–10 Ω for 920V input flyback) | ___ Ω |
| AX-R04 | Measure each secondary winding DCR | LCR meter, 1 kHz | Per design (typically 0.1–2 Ω) | VDRV_AC: ___ Ω, VDRV_DC: ___ Ω, Logic: ___ Ω |
| AX-R05 | Verify no short: DC bus input+ to input− | DMM | >1 MΩ (capacitors should not short) | ☐ P / ☐ F |
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

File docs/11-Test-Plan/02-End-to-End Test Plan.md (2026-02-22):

---
tags: [PDU, testing, V&V, certification, HALT, environmental, type-test, production-test]
created: 2026-02-22
status: draft
---

# End-to-End Test Plan — 30 kW PDU

> [!summary] Purpose
> This document defines the **full verification and validation (V&V) test plan** for the 30 kW PDU, covering the lifecycle from design verification through certification and production release. It fills the gap between the [[11-Test-Plan/01-Board-Level Test Procedure|Board-Level Test Procedure]] (prototype bring-up / DVT) and the [[12-Project-Management/03-Commissioning Procedure|Commissioning Procedure]] (field deployment). It provides the detailed test procedures, acceptance criteria, and test matrices referenced by [[12-Project-Management/Epics/EP-08 Pre-Production Validation|EP-08 Pre-Production Validation]] stories.

---

## 1. Test Strategy Overview

### 1.1 Test Phases

| Phase | Abbreviation | Purpose | Units | Primary Venue |
|---|---|---|---|---|
| Design Verification Test | DVT | Prove the design meets specifications on prototype hardware | Rev A / early Rev B | In-house lab |
| Engineering Validation Test | EVT | Formal type testing, environmental qualification, reliability | Rev B (design-frozen) | In-house + accredited lab |
| Production Validation Test | PVT | Validate production test fixtures, process, and yield | Pilot production run | Factory / contract manufacturer |

### 1.2 Scope Mapping

| Test Category | DVT | EVT | PVT | Reference |
|---|:---:|:---:|:---:|---|
| Board-level bring-up (§3 of board-level procedure) | X | | | [[11-Test-Plan/01-Board-Level Test Procedure\|01-Board-Level Test Procedure]] §3 |
| System integration (§4 of board-level procedure) | X | | | [[11-Test-Plan/01-Board-Level Test Procedure\|01-Board-Level Test Procedure]] §4 |
| Efficiency sweep | X | X | | §2 below; board-level §4.2 |
| Type tests per standards (§3 below) | | X | | Accredited lab |
| Environmental qualification (§4 below) | | X | | Environmental test lab |
| HALT / burn-in (§5 below) | | X | | In-house or contract |
| Communication protocol validation (§6 below) | X | X | | In-house lab |
| Charging profile tests (§7 below) | X | X | | In-house + vehicle test |
| Production test (§8 below) | | | X | Factory |

### 1.3 Relationship to Other Documents

| Document | Role |
|---|---|
| [[11-Test-Plan/01-Board-Level Test Procedure\|01-Board-Level Test Procedure]] | DVT-phase procedures — standalone board tests and first system integration |
| [[12-Project-Management/03-Commissioning Procedure\|Commissioning Procedure]] | PVT/field — site acceptance testing for deployed units |
| [[12-Project-Management/Epics/EP-08 Pre-Production Validation\|EP-08 Pre-Production Validation]] | Project management stories defining schedule, assignees, and gate criteria for EVT activities |
| [[09-Protection and Safety]] | Protection thresholds, hipot voltages, safety compliance matrix — normative reference for type tests |

---

## 2. Requirements Traceability Matrix

Every key specification from [[__init]] is mapped to one or more test cases. Test IDs prefixed **RTM-** are traced here; detailed procedures appear in subsequent sections.

| # | Specification | Value | Test ID(s) | Test Phase | Section |
|:-:|---|---|---|:---:|:---:|
| 1 | Input voltage range | 260–530 VAC, 3-phase | RTM-01 | DVT, EVT | §3.1 |
| 2 | Input frequency range | 45–65 Hz | RTM-02 | DVT | §3.1 |
| 3 | Input current | ≤60 A per module | RTM-03 | DVT | §3.1 |
| 4 | Power factor | ≥0.99 at full load | RTM-04 | DVT, EVT | §3.1 |
| 5 | THDi | ≤5% at full load | RTM-05 | DVT, EVT | §3.1 |
| 6 | Rated output power | 30 kW (constant power) | RTM-06 | DVT, EVT | §3.1 |
| 7 | Output voltage range | 150–1000 VDC | RTM-07 | DVT, EVT | §3.1, §7 |
| 8 | Output current range | 0–100 A | RTM-08 | DVT, EVT | §3.1, §7 |
| 9 | Voltage accuracy | ±0.5% | RTM-09 | DVT | §3.1 |
| 10 | Current accuracy | ±1% | RTM-10 | DVT | §3.1 |
| 11 | Output ripple | <0.5% RMS | RTM-11 | DVT | §3.1 |
| 12 | Peak efficiency | >96% | RTM-12 | DVT, EVT | §3.1 |
| 13 | Standby power | <8 W | RTM-13 | DVT | §3.1 |
| 14 | Soft start time | ≤6 s | RTM-14 | DVT | §3.1 |
| 15 | MTBF | >120,000 hours | RTM-15 | EVT | §5 |
| 16 | CAN stacking — current imbalance | ≤5% | RTM-16 | DVT, EVT | §6.2 |
| 17 | Acoustic noise | ≤65 dB | RTM-17 | DVT, EVT | §3.1 |
| 18 | Operating temperature | −30°C to +55°C full load | RTM-18 | EVT | §4.1 |
| 19 | Storage temperature | −40°C to +85°C | RTM-19 | EVT | §4.2 |
| 20 | Protections (OVP/OCP/OTP/SC/surge) | Per [[09-Protection and Safety]] §8 | RTM-20 | DVT, EVT | §3.2, §3.3 |
| 21 | IEC 61851-23 compliance | DC EVSE requirements | RTM-21 | EVT | §3.2 |
| 22 | IEC 62368-1 compliance | Equipment safety | RTM-22 | EVT | §3.1 |
| 23 | UL 2202 compliance | North American listing | RTM-23 | EVT | §3.3 |
| 24 | CE marking (EMC) | EN 55032, EN 61000-4 series | RTM-24 | EVT | §3.4 |
| 25 | Dimensions | ~455 × 300 × 94 mm | RTM-25 | DVT | Mechanical inspection |
| 26 | Weight | ~17 kg | RTM-26 | DVT | Mechanical inspection |

---

## 3. Type Tests per Standards

### 3.1 IEC 62368-1 — Equipment Safety

| Test | Clause | Description | Level / Condition | Pass Criteria |
|---|---|---|---|---|
| Hipot: AC input → PE | 5.4.1 | Dielectric withstand | 3000 VAC, 60 s | No breakdown; leakage <5 mA |
| Hipot: DC bus → PE | 5.4.1 | Dielectric withstand | 3500 VAC, 60 s | No breakdown; leakage <5 mA |
| Hipot: DC output → PE | 5.4.1 | Dielectric withstand | 3750 VAC, 60 s | No breakdown; leakage <5 mA |
| Hipot: primary → secondary | 5.4.1 | Reinforced insulation | 4000 VAC, 60 s | No breakdown; leakage <5 mA |
| Partial discharge | 5.4.1 | Insulation integrity | 2880 Vpk (1.5× working) | <10 pC |
| Touch current | 5.4.9 | Normal operation | Rated voltage, MD network | <3.5 mA |
| Earth bond | 5.4.1 | Protective earth | 25 A for 60 s | <0.1 Ω |
| Temperature rise | 5.4.7 | All components | Rated load, max ambient | No component exceeds rated limit |
| Abnormal operation | 5.4.6 | Single-fault safety | Blocked fan, shorted output, open feedback | No fire, no hazardous voltage exposure |

> [!note] Hipot levels from [[09-Protection and Safety]] §7.2.

### 3.2 IEC 61851-23 — DC EV Charging

| Test | Clause | Description | Level / Condition | Pass Criteria |
|---|---|---|---|---|
| Output voltage limits | 6.3.1 | OVP response | 105% setpoint (SW), 1100 V (HW) | LLC off <100 µs (SW), <1 µs (HW); contactor opens |
| Output current limits | 6.3.2 | OCP response | 110 A cycle-by-cycle, 120 A hardware | Pulse skip / latch per [[09-Protection and Safety]] §3.1 |
| Short circuit | 6.3.3 | Output short-circuit | Bolted short at output terminals | DESAT <2 µs, all PWM off, contactor opens |
| Insulation monitoring | 8.2 | Pre-charge and continuous | >500 kΩ pre-charge, >100 kΩ operational | IMD trips and opens contactor if below threshold |
| DC residual current | 9.4 | Ground fault detection | >6 mA DC residual | RCM trips <1 s per IEC 62955 |
| Emergency stop | 6.3.1 | De-energization | E-stop activation at full load | V_bus <60 V within 5 s |
| Output de-energization | 6.3.1 | Normal shutdown | Shutdown command | V_bus <60 V within 5 s |

### 3.3 UL 2202 — EV Charging Equipment

| Test | Section | Description | Condition | Pass Criteria |
|---|---|---|---|---|
| Overload | §29 | Sustained overcurrent | 120% rated current, 60 min | Protection operates; no fire or hazard |
| Short circuit | §30 | Bolted short | Output terminals shorted | Safe shutdown; no explosion or fire |
| Temperature | §36 | All accessible surfaces | Rated load, max ambient | Touchable surfaces <65°C at 25°C ambient |
| Abnormal operation | §28 | Blocked ventilation, component failure | Single-fault conditions | No hazard; protection operates correctly |
| Dielectric withstand | §26 | Hipot | Per IEC 62368-1 levels | No breakdown |
| Leakage current | §27 | Normal operation | Rated voltage | <3.5 mA |
| Ground fault | §31 | DC ground fault | >6 mA DC | RCM trips within 1 s |

### 3.4 EMC — EN 55032 + EN 61000-4 Series
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

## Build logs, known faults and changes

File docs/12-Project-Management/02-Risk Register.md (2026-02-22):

---
tags: [PDU, project-management, risk, management]
created: 2026-02-22
aliases: [Risk Register, 05-Risk Register]
---

# Risk Register

This document identifies and tracks risks for the 30 kW PDU development programme, categorized by type with likelihood, impact, and mitigation strategies.

> [!note] See [[09-Protection and Safety]] for safety-related design mitigations. Phase references align with the epics in [[12-Project-Management/__init|Project Management]].

## Risk Matrix

Risks are scored on a 5×5 matrix:

| | Impact 1 (Negligible) | Impact 2 (Minor) | Impact 3 (Moderate) | Impact 4 (Major) | Impact 5 (Critical) |
|---|---|---|---|---|---|
| **Likelihood 5 (Almost Certain)** | 5 | 10 | 15 | 20 | 25 |
| **Likelihood 4 (Likely)** | 4 | 8 | 12 | 16 | 20 |
| **Likelihood 3 (Possible)** | 3 | 6 | 9 | 12 | 15 |
| **Likelihood 2 (Unlikely)** | 2 | 4 | 6 | 8 | 10 |
| **Likelihood 1 (Rare)** | 1 | 2 | 3 | 4 | 5 |

### Risk Levels

| Score | Level | Action |
|---|---|---|
| 15–25 | **Critical** | Immediate mitigation required; escalate to project lead |
| 10–14 | **High** | Mitigation plan required; review weekly |
| 5–9 | **Medium** | Monitor; mitigation plan recommended |
| 1–4 | **Low** | Accept; review monthly |

---

## Technical Risks

### T1: LLC ZVS Loss at Light Load

| Field | Value |
|---|---|
| **Description** | LLC converter may lose ZVS (Zero Voltage Switching) below 10–15% load, causing hard switching, increased losses, and EMI |
| **Likelihood** | 3 (Possible) |
| **Impact** | 3 (Moderate) — reduced efficiency and increased EMI at light load |
| **Score** | **9 (Medium)** |
| **Phase** | 3 (Integration) |
| **Mitigation** | Burst mode at very light load; verify gain curve per [[03-LLC Gain Curve Verification]]; optimize magnetizing inductance (Lm) for wide ZVS range |
| **Owner** | PE Lead |

### T2: PFC THD Exceeds 5% Limit

| Field | Value |
|---|---|
| **Description** | Vienna rectifier THDi may exceed IEC 61000-3-2 Class A limits at partial load, especially with unbalanced input |
| **Likelihood** | 2 (Unlikely) |
| **Impact** | 4 (Major) — certification failure |
| **Score** | **8 (Medium)** |
| **Phase** | 3, 6 |
| **Mitigation** | dq-frame control with feedforward per [[06-Firmware Architecture]]; tune current loop bandwidth; verify at 25% load points |
| **Owner** | FW Engineer |

### T3: Thermal Runaway or Hotspot

| Field | Value |
|---|---|
| **Description** | Junction temperatures exceed limits under worst-case conditions (55°C ambient, 30 kW, reduced airflow) |
| **Likelihood** | 3 (Possible) |
| **Impact** | 4 (Major) — field failure or forced derating below spec |
| **Score** | **12 (High)** |
| **Phase** | 3, 7 |
| **Mitigation** | Conservative thermal design per [[04-Thermal Budget]]; multiple NTC sensors; firmware thermal derating curve; HALT testing to find margin |
| **Owner** | PE Lead |

### T4: Gate Driver Noise Causing False Triggering

| Field | Value |
|---|---|
| **Description** | High dV/dt (50+ V/ns with SiC) causes common-mode noise coupling into gate driver, causing shoot-through |
| **Likelihood** | 3 (Possible) |
| **Impact** | 5 (Critical) — immediate device destruction |
| **Score** | **15 (Critical)** |
| **Phase** | 1, 2 |
| **Mitigation** | Select gate drivers with CMTI >200 V/ns; negative turn-off bias (−5 V); Kelvin source connection; tight gate loop per [[07-PCB-Layout/__init|07-PCB Layout]]; verify with fast dV/dt on bench |
| **Owner** | PE Lead |

### T5: Resonant Component Tolerance Shifting Gain Curve

| Field | Value |
|---|---|
| **Description** | Lr, Lm, Cr tolerance stackup (±10–15%) shifts LLC gain curve, narrowing operating range |
| **Likelihood** | 3 (Possible) |
| **Impact** | 3 (Moderate) — may not cover full 150–1000 V output range |
| **Score** | **9 (Medium)** |
| **Phase** | 1, 3 |
| **Mitigation** | Specify tight tolerances on Cr (±5%); characterize actual Lr/Lm on received transformers; Monte Carlo analysis per [[03-LLC Gain Curve Verification]]; design with margin |
| **Owner** | PE Lead |

### T6: Firmware Control Loop Instability

| Field | Value |
|---|---|
| **Description** | PFC voltage loop or LLC frequency loop becomes unstable at certain operating points (e.g., mode transitions, load steps) |
| **Likelihood** | 2 (Unlikely) |
| **Impact** | 4 (Major) — OVP/OCP trip, potential hardware damage |
| **Score** | **8 (Medium)** |
| **Phase** | 3, 5 |
| **Mitigation** | Model-based loop design with adequate phase margin (>45°); extensive transient testing across operating envelope; anti-windup on integrators; slew rate limits |
| **Owner** | FW Engineer |

### T7: CAN Bus Current Sharing Instability

| Field | Value |
|---|---|
| **Description** | 5-module parallel operation shows oscillating current distribution or one module consistently overloaded |
| **Likelihood** | 3 (Possible) |
| **Impact** | 3 (Moderate) — thermal stress on overloaded module |
| **Score** | **9 (Medium)** |
| **Phase** | 5 |
| **Mitigation** | Droop sharing with CAN-based trim; test with intentionally mismatched modules; configurable droop gain; monitor imbalance threshold and alarm |
| **Owner** | FW Engineer |

---

## Supply Chain Risks

### S1: SiC MOSFET Long Lead Time

| Field | Value |
|---|---|
| **Description** | SiC MOSFETs (Wolfspeed, Infineon, onsemi) have lead times of 16–30+ weeks; risk of allocation during shortage |
| **Likelihood** | 4 (Likely) |
| **Impact** | 4 (Major) — schedule slip of 2–4 months |
| **Score** | **16 (Critical)** |
| **Phase** | 0, 4 |
| **Mitigation** | Order early in Phase 0; qualify 2 alternate sources per [[07-BOM and Cost Analysis]]; maintain safety stock for Rev B; consider broker market for prototype qty |
| **Owner** | Project Manager |

### S2: Custom Magnetics Vendor Delay

| Field | Value |
|---|---|
| **Description** | Custom-wound LLC transformer and PFC inductor depend on specialist magnetics vendor with limited capacity |
| **Likelihood** | 3 (Possible) |
| **Impact** | 3 (Moderate) — 2–4 week schedule slip |
| **Score** | **9 (Medium)** |
| **Phase** | 0–1 |
| **Mitigation** | Engage vendor in Phase 0; provide final specs early; qualify backup vendor; consider hand-winding prototypes in-house for Phase 1 |
| **Owner** | PE Lead |

### S3: Single-Source Component

| Field | Value |
|---|---|
| **Description** | Key components (specific gate driver, CAN transceiver, current sensor) may be single-source with no drop-in alternative |
| **Likelihood** | 3 (Possible) |
| **Impact** | 3 (Moderate) — re-design if component becomes unavailable |
| **Score** | **9 (Medium)** |
| **Phase** | 0, 4, 8 |
| **Mitigation** | BOM review with alternates column per [[07-BOM and Cost Analysis]]; footprint-compatible alternates where possible; qualification testing of alternates during Phase 4 |
| **Owner** | PE Lead |

### S4: Connector or Enclosure Vendor EOL

| Field | Value |
|---|---|
| **Description** | Mechanical components (connectors, enclosure hardware) may go EOL between prototype and production |
| **Likelihood** | 2 (Unlikely) |
| **Impact** | 2 (Minor) — re-source with minimal design change |
| **Score** | **4 (Low)** |
| **Phase** | 8 |
| **Mitigation** | Select components from established product lines; verify lifecycle status at BOM freeze |
| **Owner** | Mech Engineer |

---

## Schedule Risks

### SC1: PCB Fabrication Delay

| Field | Value |
|---|---|
| **Description** | PCB fabrication (6-layer, 2 oz Cu) takes longer than quoted due to fab capacity or quality issues |
| **Likelihood** | 3 (Possible) |
| **Impact** | 2 (Minor) — 1–2 week slip |
| **Score** | **6 (Medium)** |
| **Phase** | 1, 4 |
| **Mitigation** | Use established fab with track record; order 2–3 spares; consider expedite option; have backup fab identified |
| **Owner** | PCB Designer |

### SC2: Integration Debug Overrun

| Field | Value |
|---|---|
| **Description** | System integration (Phase 3) reveals unexpected issues requiring extensive debug, exceeding 8-week allocation |
| **Likelihood** | 4 (Likely) |
| **Impact** | 3 (Moderate) — 2–4 week schedule extension |
| **Score** | **12 (High)** |
| **Phase** | 3 |
| **Mitigation** | Phase 3 has 2-week buffer built into 8-week estimate; prioritize critical path items; daily debug standups; pre-validate sub-systems thoroughly in Phase 2 |
| **Owner** | PE Lead |

### SC3: EMC Test Failure Requiring Re-Design

| Field | Value |
|---|---|
| **Description** | Formal EMC test fails (conducted or radiated emissions), requiring filter re-design and re-test |
| **Likelihood** | 3 (Possible) |
| **Impact** | 4 (Major) — 4–8 week delay + $5,000–15,000 re-test cost |
| **Score** | **12 (High)** |
| **Phase** | 6, 7 |
| **Mitigation** | Thorough pre-compliance testing in Phase 6 with 6 dB margin target; iterative [[05-EMI Filter Design|EMI filter]] tuning before formal test; budget for one re-test; select lab with quick turnaround |
| **Owner** | EMC Specialist |

### SC4: Safety Certification Extended Review

| Field | Value |
|---|---|
| **Description** | Safety certification body raises additional questions or requires design modifications, extending 8-week timeline |
| **Likelihood** | 3 (Possible) |
| **Impact** | 3 (Moderate) — 4–8 week delay |
| **Score** | **9 (Medium)** |
| **Phase** | 7 |
| **Mitigation** | Engage certification body early (Phase 6) for pre-review; ensure TCF is complete before submission; design for compliance from Phase 0 per [[09-Protection and Safety]] |
| **Owner** | PE Lead |

### SC5: Lab Scheduling Conflict

| Field | Value |
|---|---|
| **Description** | Accredited EMC or safety lab has no availability when needed, pushing formal test by 4–8 weeks |
| **Likelihood** | 3 (Possible) |
| **Impact** | 3 (Moderate) — direct schedule delay |
| **Score** | **9 (Medium)** |
| **Phase** | 7 |
| **Mitigation** | Book lab slots 8–12 weeks in advance; maintain relationship with 2 accredited labs; flexible schedule to accommodate lab availability |
| **Owner** | Project Manager |

---

## Certification Risks

### C1: Emissions Above Class B at Switching Harmonics

| Field | Value |
|---|---|
| **Description** | Conducted emissions at PFC or LLC switching frequency harmonics (65 kHz, 100–300 kHz fundamental + harmonics) exceed Class B limits |
| **Likelihood** | 4 (Likely) |
| **Impact** | 3 (Moderate) — filter redesign needed |
| **Score** | **12 (High)** |
| **Phase** | 6 |
| **Mitigation** | Design EMI filter per [[05-EMI Filter Design]] with margin; CM choke + DM filter staged; near-field probing during integration to identify leakage paths; grounding optimization |
| **Owner** | EMC Specialist |

### C2: Safety Standard Revision During Project

| Field | Value |
|---|---|
| **Description** | IEC 62368-1 or IEC 61851-23 issues revised edition during project, changing requirements |
| **Likelihood** | 1 (Rare) |
| **Impact** | 4 (Major) — potential re-design for new requirements |
| **Score** | **4 (Low)** |
| **Phase** | 6–7 |
| **Mitigation** | Monitor IEC TC108 and TC69 publication schedules; design with margin beyond current edition requirements; confirm applicable edition with certification body at project start |
| **Owner** | PE Lead |

### C3: Surge Test Failure (IEC 61000-4-5)

| Field | Value |
|---|---|
| **Description** | Surge test at ±4 kV L-PE causes component damage or functional failure |
| **Likelihood** | 3 (Possible) |
| **Impact** | 3 (Moderate) — requires surge protection re-design |
| **Score** | **9 (Medium)** |
| **Phase** | 6 |
| **Mitigation** | MOV + GDT coordination per [[05-EMI Filter Design]]; pre-test with surge generator in Phase 6; adequate creepage on input filter stage |
| **Owner** | PE Lead |

---

## Financial Risks

### F1: Test Equipment Budget Overrun

| Field | Value |
|---|---|
| **Description** | Test equipment costs exceed estimate due to price increases or additional equipment needs discovered during testing |
| **Likelihood** | 3 (Possible) |
| **Impact** | 2 (Minor) — budget overrun 10–20% in equipment category |
| **Score** | **6 (Medium)** |
| **Phase** | 3 |
| **Mitigation** | Get firm quotes before Phase 3; consider rental for non-critical items; 15% contingency in budget per [[12-Project-Management/01-Budget Estimate|Budget Estimate]] |
| **Owner** | Project Manager |

### F2: Certification Cost Overrun Due to Re-Testing

| Field | Value |
|---|---|
| **Description** | Multiple EMC or safety re-tests required, each adding $5,000–15,000 |
| **Likelihood** | 3 (Possible) |
| **Impact** | 3 (Moderate) — $15,000–30,000 overrun |
| **Score** | **9 (Medium)** |
| **Phase** | 7 |
| **Mitigation** | Thorough pre-compliance in Phase 6; budget for one re-test in baseline; fix root cause before re-submission |
| **Owner** | PE Lead |

---

## Risk Summary Dashboard

| ID | Risk | L | I | Score | Level | Status |
|----|---|---|---|---|---|---|
| T4 | Gate driver noise / shoot-through | 3 | 5 | 15 | Critical | Open |
| S1 | SiC MOSFET lead time | 4 | 4 | 16 | Critical | Open |
| T3 | Thermal runaway / hotspot | 3 | 4 | 12 | High | Open |
| SC2 | Integration debug overrun | 4 | 3 | 12 | High | Open |
| SC3 | EMC test failure | 3 | 4 | 12 | High | Open |
| C1 | Emissions at switching harmonics | 4 | 3 | 12 | High | Open |
| T1 | LLC ZVS loss at light load | 3 | 3 | 9 | Medium | Open |
| T2 | PFC THD exceeds limit | 2 | 4 | 8 | Medium | Open |
| T5 | Resonant component tolerance | 3 | 3 | 9 | Medium | Open |
| T6 | Control loop instability | 2 | 4 | 8 | Medium | Open |
| T7 | CAN current sharing instability | 3 | 3 | 9 | Medium | Open |
| S2 | Magnetics vendor delay | 3 | 3 | 9 | Medium | Open |
| S3 | Single-source component | 3 | 3 | 9 | Medium | Open |
| SC1 | PCB fab delay | 3 | 2 | 6 | Medium | Open |
| SC4 | Safety cert extended review | 3 | 3 | 9 | Medium | Open |
| SC5 | Lab scheduling conflict | 3 | 3 | 9 | Medium | Open |
| C3 | Surge test failure | 3 | 3 | 9 | Medium | Open |
| F1 | Test equipment budget overrun | 3 | 2 | 6 | Medium | Open |
| F2 | Certification cost overrun | 3 | 3 | 9 | Medium | Open |
| S4 | Connector/enclosure vendor EOL | 2 | 2 | 4 | Low | Open |
| C2 | Safety standard revision | 1 | 4 | 4 | Low | Open |

**Summary:** 2 Critical, 4 High, 13 Medium, 2 Low — **21 total risks identified**

---

## Revision History

| Rev | Date | Author | Changes |
|-----|---|---|---|
| 0.1 | 2026-02-22 | Manas Pradhan | Initial draft — 21 risks identified |
| 0.2 | 2026-02-22 | Manas Pradhan | Moved from 11-Project-Plan to 12-Project-Management |

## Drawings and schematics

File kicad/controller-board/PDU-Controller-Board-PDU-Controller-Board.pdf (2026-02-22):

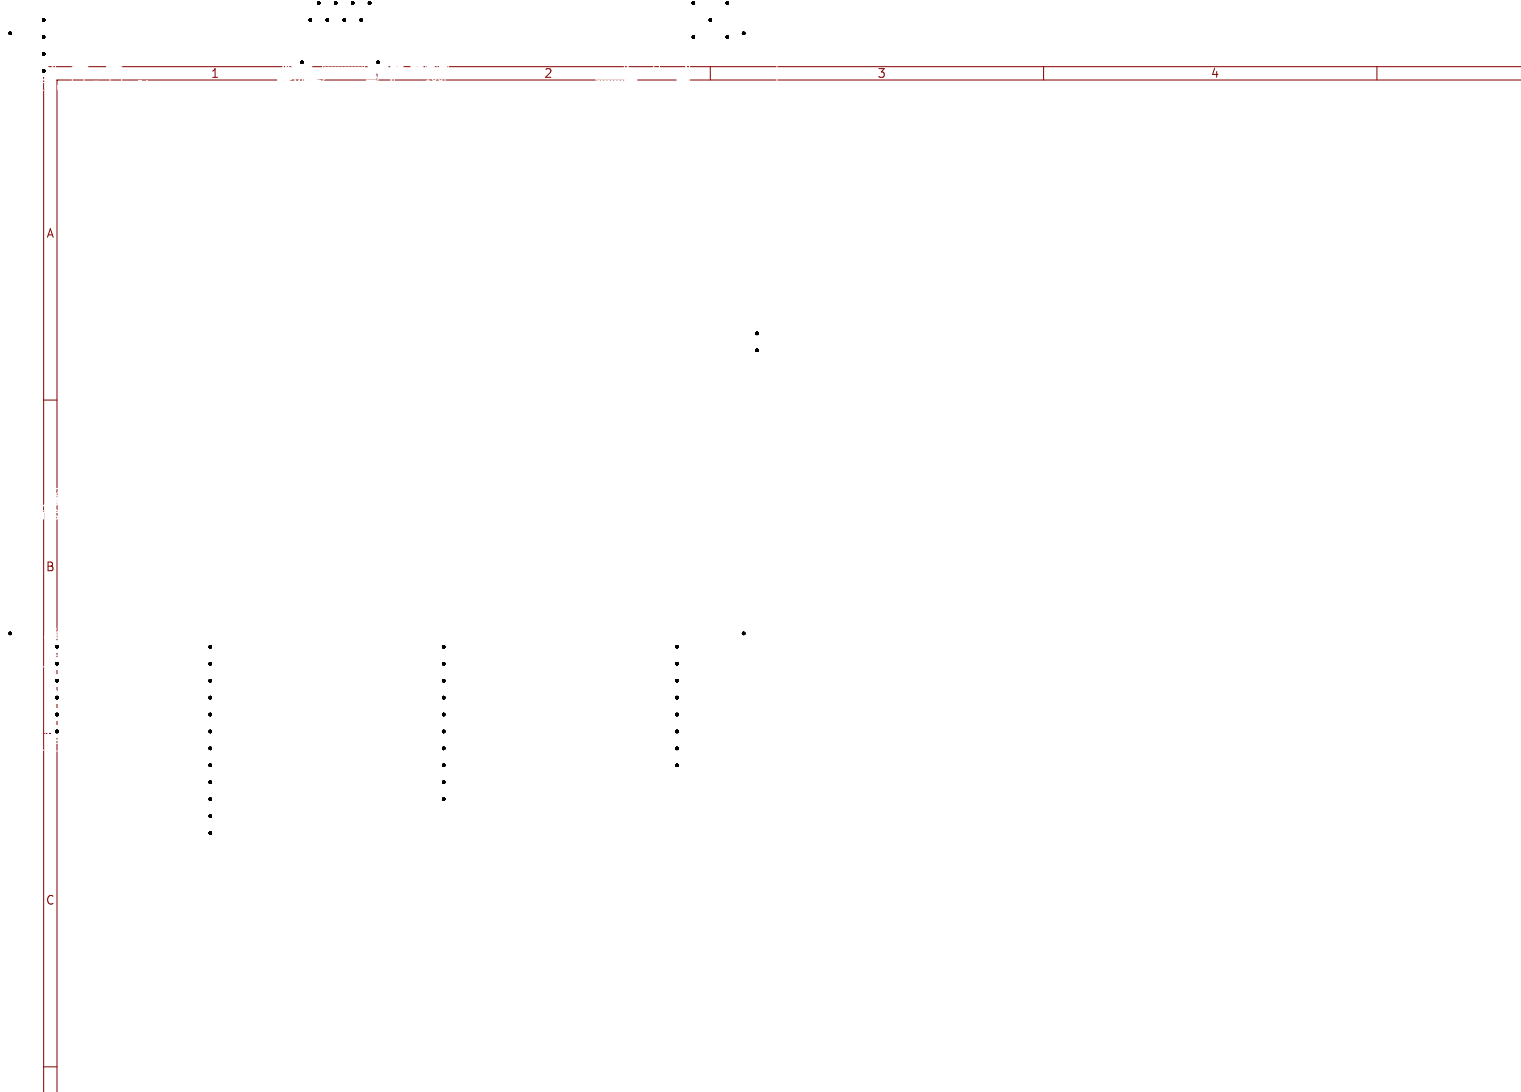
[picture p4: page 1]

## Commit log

2026-02-22 Initial commit: 30 kW PDU design documentation
    Complete design documentation set for a 30 kW Power Delivery Unit
    for DC fast EV charging (Vienna PFC + 3-phase interleaved LLC).
    Includes:
    - Project spec and topology selection
    - Magnetics design and LLC gain verification (with ngspice sims)
    - Thermal budget, EMI filter design, firmware architecture
    - BOM/cost analysis, power-on sequence, protection and safety
    - Mechanical integration (enclosure, heatsink, fan, bus bars)
    - Multi-board PCB layout (AC-DC, DC-DC, Controller, Aux-PSU)
    with per-board stack-up, power loops, gate drivers, thermal,
    EMI, and creepage/clearance documentation
    - Research notes on topology selection, SiC thermals, EMC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
2026-02-22 Add revision history tracking and fix broken wiki links
    - Add "Revision History" table to all 45 markdown documents
    - Fix broken wiki links: update partial paths to full 07-PCB-Layout/ paths
    - Rename [[05-Protection and Safety]] refs to [[09-Protection and Safety]]
    - Rename [[06-Mechanical Integration]] refs to [[10-Mechanical Integration]]
    - Create 09-Protection and Safety.md (OVP/OCP/OTP, surge, insulation, compliance)
    - Create 10-Mechanical Integration.md (enclosure, heatsink, fans, bus bars, assembly)
    - Update project __init.md with new document links
    - Remove duplicate Revision History sections from Controller/Aux-PSU/AC-DC docs
    - Rewrite 07-PCB-Layout/__init.md for multi-board architec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
2026-02-22 Add project development plan and update PCB layout docs
    Create docs/11-Project-Plan/ with 7 documents covering the full
    development lifecycle: phased schedule (9 phases, 18 months),
    test plan (35 procedures across 6 stages), resource plan, budget
    estimate ($390K–615K), risk register (21 risks), and commissioning
    procedure. Update root __init.md with link to project plan.
2026-02-22 Add sprint breakdown, firmware design docs, epics, and KiCad schematics
    - Create Sprints/ folder with 27 two-week sprint files (SP-01 to SP-27)
    mapping all 123 stories from 9 epics into time-boxed iterations
    - Add sprint index (__init.md) with cadence, capacity model, and ceremonies
    - Add 12-Project-Management section with epics (EP-01 to EP-09), budget
    estimate, risk register, and commissioning procedure
    - Add firmware design sub-documents (state machine, power-on sequence,
    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
    [PDU-AC-DC-Board.kicad_pcb, PDU-AC-DC-Board.kicad_sch, PDU-Aux-PSU-Board.kicad_pcb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]
2026-02-22 Add 11-Test-Plan folder with end-to-end test plan
    Create docs/11-Test-Plan/ to group all test documentation:
    - Move board-level test procedure into subfolder
    - Add comprehensive E2E test plan covering requirements traceability,
    type tests (IEC 62368-1, IEC 61851-23, UL 2202, EMC), environmental
    qualification, HALT/burn-in, communication protocol validation,
    charging profiles, production test spec, and certification matrix
    - Update __init.md link to point to new folder structure
    - Update CLAUDE.md with firmware repo structure
